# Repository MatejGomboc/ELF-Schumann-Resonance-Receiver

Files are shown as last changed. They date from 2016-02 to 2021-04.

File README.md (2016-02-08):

# ELF-Schumann-Resonance-Receiver
ELF Schumann Resonance Receiver

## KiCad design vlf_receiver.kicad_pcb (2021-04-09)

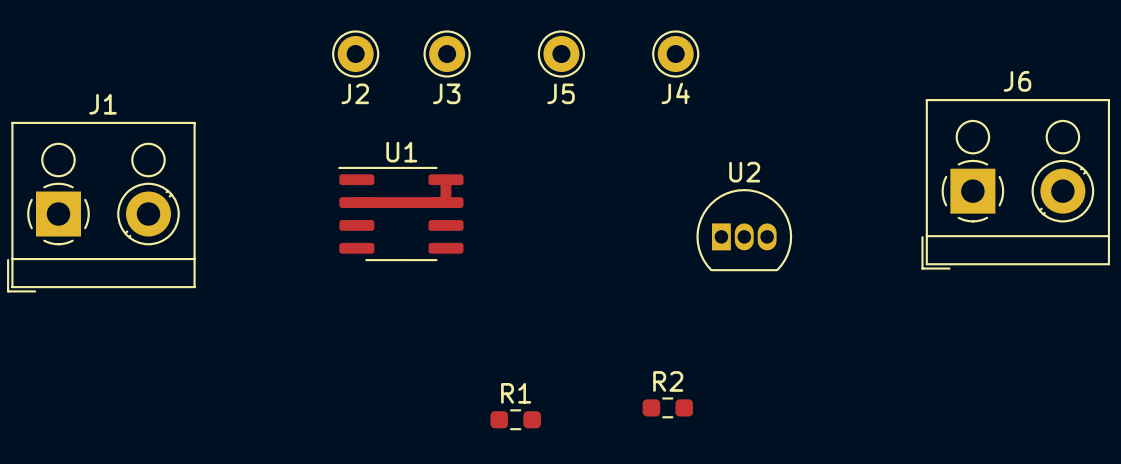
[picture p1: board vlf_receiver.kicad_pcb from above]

Board: 2 copper layers, 10 parts (0 on the bottom side), 6 nets.

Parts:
J1: OUT; TerminalBlock_RND_205-00001_1x02_P5.00mm_Horizontal
J2: ANT+; Pin_D1.0mm_L10.0mm
J3: ANT-; Pin_D1.0mm_L10.0mm
J4: BLEED-R; Pin_D1.0mm_L10.0mm
J5: FILT-C; Pin_D1.0mm_L10.0mm
J6: VCC; TerminalBlock_RND_205-00001_1x02_P5.00mm_Horizontal
R1: 100k; R_0603_1608Metric_Pad0.98x0.95mm_HandSolder
R2: 10k; R_0603_1608Metric_Pad0.98x0.95mm_HandSolder
U1: LMP7721; SOIC-8_3.9x4.9mm_P1.27mm
U2: TLE2426xLP; TO-92_Inline

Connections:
+2V5: J1.1, J3.1, J4.1, J5.1, R2.1, U2.1
+5V: J6.1, U1.6, U2.3
GND: J6.2, U1.3, U2.2
unnamed: J1.2, R1.2, U1.4
unnamed: J2.1, U1.1
unnamed: R1.1, R2.2, U1.2, U1.7, U1.8

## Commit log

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2026-03-15 Add parametric PCB capacitor generator for KiCad 9.0
    Python script generates the capacitor_square.kicad_pcb with configurable
    board size, copper pullback, substrate material, and target capacitance.
    Includes JLCPCB tolerance analysis. Default: FR4 0.8mm, 15.2mm side, ~10pF.
    [capacitor_square.kicad_pcb]
2026-03-15 Clean up capacitor_square project and gitignore KiCad artifacts
    Remove unneeded schematic, symbol lib, and footprint dir from
    capacitor_square (PCB-only project, no schematic needed).
    Remove back silkscreen GND text. Fix KiCad S-expression syntax
    (no comments, no 'justify center'). Gitignore KiCad auto-generated
    files (*-backups/, *.kicad_prl, fp-info-cache) across all projects.
    [capacitor_square.kicad_pcb, capacitor_square.kicad_sch]
2026-03-15 Add JLCPCB DRC rules and fix PCB generator
    Set DRC constraints to JLCPCB 2-layer 1oz FR4 capabilities:
    min clearance 0.1mm, min track 0.1mm, min via 0.25mm, min drill 0.2mm,
    min silk height 1.0mm, min silk width 0.153mm, Cu-to-edge 0.2mm.
    Remove GND back silkscreen. DRC passes clean (0 violations).
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2026-03-15 Fix gerber plot settings in PCB for JLCPCB compatibility
    Enable Protel file extensions and subtract-soldermask-from-silkscreen
    in the stored board plot parameters, so manual exports from KiCad's
    Plot dialog also produce JLCPCB-compatible output by default.
    [capacitor_square.kicad_pcb]
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2026-03-15 Redesign PCB cross-section diagram
    Rewrite cross-section with better alignment: PCB only spans antenna
    amp ALU, PSU clearly separate, filter chain moved below PCB with
    antenna symbol, output wire goes up into Comp 1, tighter layout
    with no overlapping labels.
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2026-03-20 Add DC resistance and ESR analysis, air-gap capacitor option
    Add volume resistivity data and DC leakage resistance calculation
    for all substrates. Add dielectric ESR (tan delta) analysis showing
    FR4's 40 MOhm ESR at Schumann frequencies destroys the LMP7721's
    noise advantage. Add air-gap capacitor as new preferred option:
    two masked PCBs with spacers, zero ESR, infinite R_dc, 16mm plates
    at 0.2mm gap for 10pF. Plot now has 3 panels: C, R_dc, and fc.
2026-03-20 Replace PCB-substrate capacitors with air-gap design
    Delete capacitor_square KiCad project (generate_pcb.py, export_gerbers.py,
    PCB files). Air-gap plate capacitors are superior: infinite R_dc, zero ESR,
    zero dielectric loss — preserving the LMP7721's femtoampere noise floor.
    FR4 substrate R_dc (40 MOhm) generates 2000x more current noise than
    the LMP7721, making PCB-dielectric caps unsuitable.
    Update all docs (PLAN.md, README.md, CLAUDE.md), diagrams ("PCB Cap" ->
    "Air Cap"), and simulation references. Geometry simulator retained in
    simulations/capacitor_square/ with air-gap as new primary option.
    [capacitor_square.kicad_pcb]
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2026-03-20 Add preamp noise analysis simulation
    LMP7721 input-referred noise model with 1/f corner, current noise,
    and PCB leakage contributions. Compares against AD820 (Romero),
    ADA4530-1, and OP27 (BJT cautionary example).
    Key results at 7.83 Hz (1st Schumann, 100 pF antenna):
    - LMP7721: 31.7 nV/sqrtHz (voltage noise + PCB leakage dominate)
    - AD820: 168 nV/sqrtHz (current noise dominates)
    - Improvement: 5.3x voltage, 28x power
    - Guard ring critical: 64x noise reduction vs unguarded
2026-03-20 Switch LDO from LT3042 to ADM7150, add 9V DC bus architecture
    Power architecture: 9V DC unregulated input (battery or AC-DC PSU)
    -> ADM7150-5.0 for +5V analog (LMP7721, LMP7715, PCM1808 VCC)
    -> ADM7150-3.3 for +3.3V digital (PCM1808 VDD, CS8406)
    ADM7150 advantages: factory-calibrated fixed output (no trim resistor),
    1.6 uV RMS noise, 800 mA, SOIC-8. Same part family for both rails.
    Also adds all KiCad symbols: LMP7721, LMP7715, PCM1808, CS8406, ADM7150.
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2026-03-20 Update design: dual SPDIF outputs, DIP switches, MEMS clock, noise ref channel
    Major design decisions:
    - Dual outputs: AES/EBU balanced (S22083) + S/PDIF coax (S22082/RCA)
    - CS8406 in hardware mode with DIP switches for format selection
    - PCM1808 sample rate configurable via DIP switches (48/64/96 kSPS)
    - 24.576 MHz MEMS oscillator replaces crystal + buffer (lower EMI)
    - Right ADC channel as noise reference (VINR tied to VREFR) for
    real-time system noise floor calibration in PC software
    - Cat6 STP cable for AES/EBU long runs
2026-03-20 Add passive noise budget and feedback tradeoff simulations
    passive_noise_budget.py: reveals filter resistors (1M) dominate noise
    at 128.7 nV/sqrtHz each, dwarfing LMP7721's 6.5 nV.
    feedback_tradeoff.py: compares R2/C3 configs. R2=20k + C3=10nF gives
    same gain curve as old 2M/100pF design but 10x less R2 noise (18.2 vs
    182 nV). Pure follower only 0.1 dB better SNR.
2026-03-20 Add filter resistor optimisation simulation
    Reveals 1M filter resistors (128.7 nV each) dominate the noise budget,
    making ELARA WORSE than Romero at SR1 despite the superior LMP7721.
    Optimal R=100k with 100pF air-gap caps gives 2.4x improvement over
    Romero. R=220k is the conservative choice at 1.8x improvement.
    Fix dB calculation (20*log10 for magnitude, not 10*log10).
2026-03-20 Add antenna capacitance calculator and corrected signal loss model
    Calculate antenna C from physical dimensions using NBS/Grover formula.
    ELARA design (10m vert + 15m top hat) = ~140 pF.
    Full complex transfer function for 2-stage RC with capacitive source.
    Key finding: R=220k is optimal (151 nV eff noise at SR1 with 140 pF
    antenna). Signal loss -4.3 dB is the price for -152 dB FM rejection.
    With larger antennas (350+ pF), ELARA beats Romero's AD820 design.
2026-03-20 Fix filter magnitude bug in feedback_tradeoff.py, verify all formulas
    Fix 2-stage filter magnitude: was sqrt(1/(1+(f/fc)^2)) which gives
    |H| for 1 stage, should be 1/(1+(f/fc)^2) for |H| of 2 stages.
    Independent verification of all key calculations:
    - Thermal noise, antenna C, source Z, current noise, cap divider,
    full complex transfer function, FM rejection all confirmed correct.
2026-03-20 Fix ADC noise floor calculation (was 2.9x too high)
    PCM1808: 3 Vpp = 1.06 Vrms (not 3V). With 99 dB SNR:
    noise = 11.9 uV RMS = 76.8 nV/sqrtHz (was 34 uV / 219 nV).
    Deep verification confirms all other formulas correct:
    transfer function limits, thermal noise, antenna C, gain formula,
    noise referral math, numerical stability. R_filt noise model is
    slightly conservative at VLF (safe overestimate).
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2026-03-21 Populate antenna_amplifier schematic with full signal chain
    Place all ICs (LMP7721, LMP7715, PCM1808, CS8406, 2x ADM7150),
    passive components (R1/R3 220k filter, R2 1k + C3 4.7u feedback,
    R4 470R guard drive), connectors (ANT_IN, SPDIF_OUT, PWR_IN),
    and power symbols (+9V, +5VA, +3V3D, GND).
    Wire signal path: antenna → RC filter → LMP7721 preamp with
    frequency-dependent feedback → PCM1808 ADC (I2S) → CS8406
    SPDIF TX → output connector. Guard driver (LMP7715 unity-gain)
    drives PCB guard ring. Dual ADM7150 LDOs for analog/digital
    supply rails.
    All CS8406 config pins tied for HW mode, I2S input, 256fs.
    Netlist verified correct (28 nets, 0 unconnected pins).
    Remaining ERC: lib_symbol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
    [antenna_amplifier.kicad_sch]
2026-03-22 Fix preamp feedback, add bias/oscillator/AA filter (Phases 1-4)
    Phase 1 — Fix feedback network for 20 dB ELF gain:
    R2→Rf (9.1k), C3→Cf (150nF) in parallel IN-→VOUT,
    add Rg (1k) from IN-→BIAS_MID. G=10.1 (20dB) flat across
    ELF, rolls off above 117 Hz. Correct single-supply biasing
    via 2.5V BIAS_MID reference.
    Phase 2 — Add antenna bias circuit (§3.7):
    U7 LMP7715 unity-gain follower, R5/R6 47k matched divider
    (+5VA→GND → 2.5V), C7 4700µF bypass, C8 100nF supply bypass,
    J4 jumper header for physical antenna connection.
    BIAS_MID net shared with preamp Rg reference.
    Phase 3 — Add 24.576 MHz MEMS oscillator:
    Y1 MEMS_OSC with R_S 33R series resistor, C9 100nF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
    [antenna_amplifier.kicad_sch]
2026-03-22 Add transformers, fix config pins, update PLAN.md (Phases 5-8)
    Phase 5 — Add audio transformers + dual output:
    TR1 (S22082) for S/PDIF coax → J2 RCA,
    TR2 (S22083) for AES/EBU balanced → J5 connector.
    Coupling caps C_T1/C_T2 (100nF) on primaries.
    Both driven from CS8406 TXP/TXN simultaneously.
    New XFMR_Audio symbol added to project library.
    Phase 6 — Fix PCM1808 config for 96 kSPS default:
    MD1 changed from GND to +5VA (MD1=H, MD0=L → 256×fs).
    Phase 8 — Update PLAN.md:
    - Revised §3.1: new feedback topology (Rf=9.1k, Cf=150nF,
    Rg=1k to BIAS_MID), 20 dB flat ELF gain, 117 Hz rolloff
    - Documented ELF-only design decision (VLF dropped)
    - Updated §3.4: simplif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
    [antenna_amplifier.kicad_sch]
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2026-03-22 Optimise input filter: R=33k, C=50pF for 2.3x noise reduction
    Change filter resistors from 220k to 33k and caps from 45pF to
    50pF (100pF total). This dramatically reduces the dominant noise
    source (filter R thermal noise) while maintaining adequate RF
    rejection:
    - Noise at antenna: 64.6 nV/rtHz (was 149.6 -> 2.3x better)
    - 3.2x better than Romero AD820 at SR1
    - FM rejection: -121 dB (was -154, still massive)
    - AM rejection: -41 dB (adequate for 15km AM tower)
    - Cap divider: -4.7 dB (was -4.3, acceptable)
    Key insight: the RF filter doesn't need a low cutoff (96.5 kHz
    is fine) because ELF band shaping is done by the preamp feedback
    (117 Hz) and AA filter (159 Hz). The filter's only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
    [antenna_amplifier.kicad_sch]
2026-03-22 Upgrade ADC from PCM1808 to PCM1804 (192kHz, 112dB DR)
    Replace PCM1808 (96kHz, 99dB SNR, 14-pin TSSOP) with PCM1804
    (192kHz, 112dB DR, 28-pin SSOP) for maximum SPDIF fidelity.
    ADC noise floor drops from 54.3 to 16.1 nV/rtHz (3.4x better).
    The ADC is now transparent — its noise is below the preamp's
    input-referred noise. System is entirely analog-limited.
    Key specs: 5V analog + 3.3V digital (same rails), differential
    input (VINL- tied to VCOML for single-ended), I2S output,
    128/256/384/512/768 fs clock ratios.
    For 192kHz: OSR2=H, OSR1=H, OSR0=H (quad rate, 128xfs).
    Existing 24.576 MHz oscillator works perfectly.
    New PCM1804 symbol added to project library (28-pin SSOP).
    Schematic wiring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
    [antenna_amplifier.kicad_sch]
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2026-03-22 Polish schematic: fix Y1 wire, add J2/J5 GND, connectivity check
    Fixed Y1 oscillator output wire: Y coordinate 154.94 -> 149.86
    to match actual MEMS_OSC pin 3 position. Y1 now fully connected.
    Added GND connections to J2 (SPDIF_COAX) and J5 (AES_EBU)
    connector pin 2 (shield/ground).
    Connectivity check results:
    All components fully wired except U1 pin 5 (NC) and U3 pin 20
    (OVFR) which are intentional no-connects.
    Remaining ERC items for KiCad GUI cleanup:
    - TR1/TR2 secondary wiring to connector pins (coordinate fix)
    - R_bias pin 2 position (needs update for PCM1804 VINL+)
    - C9 pin 1 connection (bypass cap wire)
    - Stale wire fragments from manual editing (15 endpoints)
    - Off-g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
    [antenna_amplifier.kicad_sch]
2026-03-22 Fix all pin connections using kicad_wirer tool
    Used tools/kicad_wirer.py to compute exact pin positions and
    fix all wire routing errors:
    - TR1/TR2 secondary pins: fixed S2 wire endpoints to match
    J2/J5 connector pin 2 positions (was off by ~5mm)
    - R_bias: rewired pin 1 to PCM1804 VCOML (pin 3) and pin 2
    to VINL+ (pin 4) for correct single-ended input biasing
    - C9: added +3V3D power connection, removed zero-length wire
    - Y1: already fixed in previous commit
    Connectivity check: ALL components fully wired.
    Only intentional no-connects remain (U1 NC, U3 OVFR).
    ERC pin_not_connected: 4 -> 0
    [antenna_amplifier.kicad_sch]
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2026-09-27 Rebuild antenna amplifier schematic from a generated netlist
    The previous schematic merged most ground, supply and several signal
    pins into a single +5VA net (a stray wire and stacked power symbols),
    so it could not be laid out. The schematic is now generated by
    PCB/antenna_amplifier/design.py via a small KiCad 9 writer in
    tools/kicadgen, and KiCad's own netlist export is checked against the
    intended nets on every run (109 parts, 68 nets, exact match).
    Circuit changes, all documented on the sheets:
    - Cg returns to GND instead of the 2.5 V bias buffer (removes the
    buffer's noise from the gain path, ~0.9 dB at SR1 per SPICE).
    - Guard buffer senses IN- rather than IN+, so its bias current ne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
    [adc.kicad_sch, antenna_amplifier.kicad_sch, digital.kicad_sch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]
2026-09-27 Add two-bucket isolated PSU and the PC analysis software
    PSU (PCB/acdc_converter/design.py, generated schematic, ERC clean):
    Mains -> IRM-05-15 -> LM317 constant-current (0.2 A) / constant-voltage
    (10.9 V) supercap charger -> two 4 x 10 F buckets swapped every ~30 s by
    two Omron G6K-2 DPDT relays wired in opposite senses. Form-C contacts
    break before make, so the receiver ground is never connected to the
    charger side; the only coupling left is the open-contact capacitance
    (~1 pF) instead of the AC-DC barrier (20-100 pF). The receiver side
    adds a reservoir, an LT3045 (0.8 uV rms, EN/PGFB to IN, 22 uF C_SET for
    low 1/f noise) and a common-mode choke. Charger ground is bonded to PE
    and the encl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
    [acdc_converter.kicad_sch, adc.kicad_sch, power.kicad_sch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]
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2026-09-30 Place the two-bucket PSU board (150 x 90 mm, unrouted)
    AC-DC module upright on the left (mains terminal, fuse and MOV below
    it), charger and swap timer across the top, relays and the two bucket
    rows in the middle with balancing resistors under the cells, receiver
    side with LT3045, CMC and output header on the right.
    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
    [acdc_converter.kicad_pcb]
2026-09-30 Add the air-gap plate capacitor PCB (64 x 64 mm, DRC clean)
    53.1 mm copper square with R4.8 reliefs at the corner M3 holes, bare
    7 mm landing rings under the 0.5 mm PTFE washers, offset solder tab so
    a flipped pair never overlaps: 48.9 pF bare / 51.9 pF masked, matching
    mechanical/params.py. Also notch the amplifier guard-island keep-out
    around U201 pins 3/4 so IN- and GND stay routable.
    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
    [plate_capacitor.kicad_pcb]
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2026-09-30 Add fab-output script; plate capacitor Gerbers/drill; router fixes
    tools/fab_outputs.sh exports Gerbers + Excellon (zipped for JLCPCB),
    pick-and-place, grouped BOM, PDFs and a 3D render per board. The
    amplifier's ANT_BIAS is pre-routed out of the guard island through the
    ring gap; Freerouting runs without its optimiser; PSU finish stage
    pours separate charger (GND_C) and receiver (GND) grounds.
    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
    [plate_capacitor_pos.csv]
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2026-09-30 Apply simulation fixes; add PSU/stability/system sims and priced BOM
    simulations/psu: the charger caps each bucket at ~10.3 V, so the LT3045
    at 8.45 V dropped out. Now R_SET 69.8k (6.98 V) and a 15 s swap
    (CD4060 Rt 80.6k): +1.97 V headroom nominal, +0.49 V worst corner.
    Charger output cap 10 uF -> 100 nF (3 A cold-start contact spike).
    Swap artefact >= 83 dB below the floor; 50 Hz leakage 4-5 orders lower
    than a direct AC-DC module (earth the receiver ground locally).
    simulations/stability: guard buffer U202 had 43 deg worst-case phase
    margin -> new C205 220 pF C0G GUARD-GND (56 deg). Others pass.
    simulations/system: chain matches SPICE (45.8 nV/rtHz at SR1), ADC
    transparent, 21 mV rms 50 H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
    [adc.kicad_sch, antenna_amplifier_bom.csv, digital.kicad_sch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]
2026-09-30 PSU board re-routed with the simulation fixes; fab outputs
    Gerbers + drill (JLCPCB zip), pick-and-place, BOM, schematic and
    assembly PDFs, 3D render in PCB/acdc_converter/fab/. DRC: fully
    connected, one starved thermal relief on C4 (benign).
    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
    [acdc_converter.kicad_pcb, acdc_converter_bom.csv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]
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2026-09-30 Leaded SOT23-5 oscillator (SiT2001B, Y402) fitted; SiT1602 kept as do-not-fit alternative
    Hand-soldering friendly: Y402 sits under Y401 between the two clock series
    resistors, both wired to OSC_OUT (outputs typed tri-state; fit only one).
    Board re-routed: 0 DRC errors, 0 unconnected. Fitted parts get silkscreen
    label priority over do-not-fit ones. Fab outputs now include populated STEP
    models of both boards; BOM, assembly guide and open checks updated.
    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
    [acdc_converter.step, antenna_amplifier.kicad_pcb, antenna_amplifier.step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]
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2026-09-30 Title blocks (rev 0.2) on all boards; PSU starved thermal fixed (C4 ground pad solid) -- PSU DRC fully clean
    Fab packages regenerated for all three boards.
    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
    [acdc_converter.kicad_pcb, acdc_converter.step, antenna_amplifier.kicad_pcb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]
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2026-09-30 Pedantic DRC/ERC pass: schematic parity clean, BNC notch, island without silk
    - Board nets carry the schematic's names (sheet-path prefix on local nets, KiCad's
    unconnected-(...) nets on open pins): DRC schematic parity 0 on both boards.
    - BNC: its mounting lugs reached 1.4 mm under the right-hand wall, whose round
    barrel hole left the bar resting on them (tilted wall, BNC shell = S/PDIF return
    shorted to the shield). The frame now has a 16 x 14 mm notch there, and the
    strip copper stops clear of the lugs. Micro-Fit notch widened to 14 mm.
    - Guard island: mask opening follows the island outline; LMP7721 and the bias link
    use project footprint variants without silk on the island (no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
    [acdc_converter.kicad_pcb, acdc_converter.step, acdc_converter_bom.csv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]
2026-09-30 Pedantic schematic and silkscreen pass: zero overlaps, labels clear of tracks
    Schematics
    - tools/kicadgen/schcheck.py checks KiCad's own SVG rendering (exact stroke boxes)
    for text over text, lines through text, crowded twin labels and text outside the
    frame. Both schematics: 0 findings; ERC 0 on both.
    - Generator: Sheet.join (one wire + one label instead of two facing labels),
    per-symbol field positions, per-pin stub lengths, shared power symbol for
    adjacent top/bottom rail pins, crowded rail runs get one label, longer PCM1804
    pins (no-connect cross clear of the pin number), PE value clear of its symbol.
    - Fixed: doubled VIN_RAW/BIAS_DIV/LED_OVF/CV_ADJ/LED_C labels, +5VA vs VREG,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
    [acdc_converter.kicad_pcb, acdc_converter.kicad_sch, acdc_converter.step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]
2026-09-30 Outdoor unit: antenna gland 10 mm right so the lead no longer hides the R1 engraving (clash check 0)
    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
    [elara_outdoor_unit_full.step, outer_box_body_generic.step]
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2026-10-02 PSU re-layout: cables can be fitted, LM317s tab-down, isolated H2/H4
    The audit against the PSU box found the board could not be wired:
    - J1's wire entry faced the fuse clips 5 mm away; the mains gland sat in
    front of the IRM-05. J1 now faces the mains gland across a 17 mm
    parts-free bay (a no-footprint rule area).
    - J2's mating face was 6 mm from the box wall, too close for the plug.
    It now looks at the output gland across a 24 mm free channel.
    - H2/H4 standoffs (on PE) sat on the receiver GND pour behind only the
    solder mask: 5 mm copper keep-outs on both layers now.
    - The clip-on heatsinks had no reserved space: the LM317s lie tab-down
    on copper areas of their OUT nets (stitched,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
    [acdc_converter.kicad_pcb, psu.kicad_sch]
2026-10-02 Amplifier: single BNC, pluggable AES3, real 63 V Cg, wall clearances
    From the placement and parts audit:
    - J402 was an Amphenol 031-6575, a dual stacked BNC 29 mm tall that
    could never pass the 14 mm wall notch. Now a single right-angle
    B6252HB-NPP3G-50 (KiCad model), body inside the compartment and
    only the nut/barrel through the notch.
    - J401's screw terminals sat under the right wall (screws at x = 194,
    wall from 193) and the shield mounts lid-down, so the AES3 cable could
    not be wired in place. Now a Phoenix MC 1,5/3-G-3,81 right-angle
    header: the MC 1,5/3-ST-3,81 plug is wired outside and pushed in
    through the notch (16 x 13 mm).
    - C202's order code was the 100 VDC WIMA (2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
    [acdc_converter.kicad_pcb, adc.kicad_sch, antenna_amplifier.kicad_pcb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]
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2026-10-03 AES3 source resistors 22 ohm for a 111 ohm source; tidy schematics and assembly drawings
    - R412/R413 2 x 39 -> 2 x 22 ohm (Vishay TNPW060322R0BEEA, anti-sulfur): the
    CS8406 drivers are 33.5 ohm each at VL = 3.3 V, so 2 x 39 gave a 145 ohm
    source, outside AES3's 110 ohm +-20 %. The schematic note had used the 5 V
    figure and mis-added it.
    - AES3 sheet: transformer flipped (kicadgen gains mirror='x') and wired straight
    to R412/R413/C405 and the RJ45, no more touching AES_HOT/AES_COLD labels.
    - Stale S/PDIF and 9 V wording out of the sheets and BOM: DC input block reads
    6.98-15 V, J101 'DC IN', PSU J2 'DC OUT', reset button and clock branch say
    AES3; the legacy +9V / +9V_OUT net name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
    [acdc_converter.kicad_pcb, acdc_converter.kicad_sch, acdc_converter.step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]
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2026-10-03 PSU charger at 10.4 V so the 2.7 V cells stay in rating; charger model corrected
    The LM317 CV divider (240 R / 1.87 k) set 11.08 V, not the 10.9 V it was
    labelled with: 2.72 V per EDLC cell whenever the receiver draws nothing,
    2.83 V at the LM317's limits. R4 is now 1.74 k (10.4 V, 2.55 V per cell,
    2.70 V worst case). Board copper and placement are unchanged; only R4's
    value, the BOM and the order lists change.
    The PSU model's charger now drops 6.2 ohm x I in the CC stage below 0.2 A
    instead of a fixed 1.25 V. Re-run: 1.81 V of LT3045 headroom nominal,
    1.05 V with every corner stacked. A 30 s swap is added as an option case
    (0.36 V stacked), which replaces STATUS's unbacked claim that it dr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
    [acdc_converter.kicad_pcb, acdc_converter.kicad_sch, acdc_converter_bom.csv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]
2026-10-03 Docs audit: SPICE noise figures, J202 value, compartments and stale text fixed
    A full cross-check of the docs against the design found stale and
    conflicting statements; all are fixed here:
    - README and PLAN quote the SPICE noise (45.8 nV/rtHz at the antenna,
    26.7 at the amplifier input, 2.6x Romero) and its breakdown instead of
    the 3 dB pessimistic Python budget; the SNR row, clip level (21 mV rms,
    12.5 dB over 5 mV), ADC floor (0.7 nV/rtHz at the antenna) and input
    resistance (the J202 resistor) follow simulations/system.
    - PLAN: J202 bias reset replaces the jumper-only start-up, guard driver
    as built (senses IN-, 470 R + 220 pF), compartments as placed, no VLF
    compensation clai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
    [antenna_amplifier_bom.csv, digikey_bom.csv, extras.csv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]
2026-10-03 LMP7721 pinout corrected: inputs on pins 1/8, OUT on 4, V+ on 6, V- on 3
    The project symbol had IN- on pin 3, GND on 4, OUT on 6 and V+ on 8; as
    drawn, the board would have shorted the op-amp's output to GND. The
    LMP7721 has both inputs at one end (1 = +IN, 8 = -IN), the N/C isolation
    pins 2 and 7 (tied to the guard) next to them, V- on 3, OUT on 4 and V+
    on 6 (TI datasheet and evaluation-board notes).
    The guard ring already suited the real pinout (inputs at the pin 1/8 end,
    guard bar under the body joining pins 2 and 7). Re-placed around U201:
    Rf, Cf, Rg and the guard buffer in one column north-east of the chip on a
    single hand-routed spine from pin 8; the guard drive (R203, C205) enters
    t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
    [amp_shield_assembly.step, antenna_amplifier.kicad_pcb, antenna_amplifier.step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]
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
